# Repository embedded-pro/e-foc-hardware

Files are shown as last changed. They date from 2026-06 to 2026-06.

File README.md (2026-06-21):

# e-foc — Hardware





A three-phase brushless (BLDC / PMSM) motor driver board designed to run the
[**e-foc** Field-Oriented Control firmware](https://github.com/embedded-pro/e-foc).

This repository contains the **KiCad** electrical design — schematics, project
configuration and (eventually) the PCB layout — for the power and signal-chain
hardware that the e-foc control software targets. The microcontroller itself
lives on a pluggable module; this board provides the power stage, gate drive,
current sensing, protection and peripheral connectivity around it.

> **Scope:** this repo is the *hardware*. For the control algorithms (Clarke/Park
> transforms, Space Vector Modulation, current/velocity PID loops, auto-tuning),
> see the [firmware repository](https://github.com/embedded-pro/e-foc).

---

## Highlights

- **Three-phase inverter** built from three TI `CSD88537ND` 60 V dual NexFET™
  half-bridge power blocks (one per phase) — low R<sub>DS(on)</sub>, sized for a
  50 V bus at 5 A.
- **`FAN7888` 3-phase gate driver** with bootstrap high-side supply for clean,
  cross-conduction-protected switching.
- **Low-side shunt current sensing** (0.02 Ω) on each phase, amplified and
  filtered through a dedicated `TLV9062` / `TLV9064` analog conditioning stage
  for the controller's ADC.
- **Wide-input switching power supply** — `LM5164` 100 V synchronous buck plus
  `AMS1117` linear regulators generating the +15 V gate-drive rail, +5 V and
  +3.3 V logic rails, with TVS bus-clamp protection (`SMCJ51A`).
- **CAN connectivity** via an `SN65HVD230` transceiver for multi-axis /
  networked control.
- **Non-volatile storage** — `24LC04` I²C EEPROM (calibration / parameters) and
  `W25Q32` 32-Mbit SPI flash (logs / firmware assets).
- **MCU-agnostic carrier** — the controller plugs in over a 24-pin (2×12)
  header, matching the firmware's `PlatformFactory` abstraction (e.g. STM32F407
  or TI Tiva TM4C1294 modules).

---

## Board architecture

The design is organised as hierarchical schematic sheets, each a self-contained
functional block:

| Sheet | Function | Key parts |
|---|---|---|
| `e-foc.kicad_sch` | Top-level sheet wiring all blocks together | — |
| `power-supply` | Wide-input supply: gate-drive + logic rails, protection | `LM5164`, `AMS1117-3.3`, `SMCJ51A` (D1 bus TVS) |
| `driver` | Three-phase inverter, gate drive, phase shunts, motor terminals | `FAN7888`, 3× `CSD88537ND`, 0.02 Ω shunts |
| `adc-conditioner` | Current/voltage sense amplification & anti-alias filtering | `TLV9062`, `TLV9064` |
| `microcontroller-connector` | 2×12 header to the MCU module + signal break-out | `Conn_02x12` |
| `can-bus` | CAN field-bus interface | `SN65HVD230` |
| `serial-com` | Serial / debug communications | — |
| `eeprom-mem` | I²C EEPROM for calibration & parameters | `24LC04` |
| `flash-mem` | SPI NOR flash for logging / assets | `W25Q32JVSS` |

---

## Design requirements (spec)

These are the **hard design targets** the board must meet — the authoritative
requirements used for design review and sign-off.

| # | Requirement | Target |
|---|---|---|
| R1 | Input bus voltage | **50 V** max |
| R2 | Output current | **5 A** max continuous (DC) |
| R3 | Motor types | 3-phase brushless (BLDC) / PMSM, **FOC** control |
| R4 | PWM switching frequency | **50 kHz** max |
| R5 | Configuration storage | **EEPROM** available for parameters / calibration |
| R6 | Firmware-update storage | **External flash** for FW update |
| R7 | Field-bus | **CAN @ 1 Mbps** max, **GND present in the connector** |
| R8 | PCB stack-up | **2 layers** is sufficient |
| R9 | Position feedback | input for **encoder OR hall sensor** |

### As-built component capability

| Parameter | Value |
|---|---|
| Power topology | 3× half-bridge (1 dual FET per phase), low-side shunt sensing |
| Switching devices | TI `CSD88537ND`, 60 V dual N-channel NexFET™ half-bridge (Q1–Q3) — 10 V margin over the 50 V bus (R1) |
| Bus TVS clamp | D1 = `SMCJ51A`, 51 V standoff / 1500 W (see note below) |
| Gate driver | `FAN7888`, 3-phase, bootstrap high-side |
| Current sense | 0.02 Ω low-side shunt per phase + op-amp gain stage |
| Logic rails | +3.3 V logic + gate-drive rail (FAN7888 VDD) |
| Protection | TVS bus clamp (`SMCJ51A`), CAN ESD array, gate clamps |
| Comms | CAN (`SN65HVD230`, R7), serial / debug |
| Storage | I²C EEPROM (`24LC04`, R5), SPI flash (`W25Q32`, 32 Mbit, R6) |
| Controller | External 24-pin MCU module (STM32 / TI Tiva, via firmware abstraction) |

> **D1 TVS sizing.** The bus is 50 V max; the `CSD88537ND` is a 60 V FET. A
> standard TVS cannot both stand off 50 V *and* clamp below 60 V (clamp ratio
> ~1.5×), so `SMCJ51A` (Vrwm 51 V, Vbr ≥ 56.7 V, Vc ≈ 82 V) is chosen to absorb
> gross load-dump / inductive transients without conducting in normal operation.
> The 10 V FET margin against **switching ringing** must be held by layout —
> tight commutation loop, adequate bulk capacitance, and (if needed) an RC
> snubber — not by the TVS. Compliance with R1–R9 is confirmed during design
> review and bring-up.

---

## Repository layout

```
e-foc/
├── hardware/                            # KiCad projects — one folder per board
│   ├── e-foc/                           #   main motor-driver board
│   │   ├── e-foc.kicad_pro
│   │   ├── e-foc.kicad_sch              #     top-level (root) schematic
│   │   ├── e-foc.kicad_pcb              #     PCB layout
│   │   ├── sym-lib-table
│   │   ├── components/                  #     project symbol libs (e.g. CSD88537ND)
│   │   └── schematic/                   #     hierarchical sub-sheets
│   │       ├── power-supply.kicad_sch
│   │       ├── driver.kicad_sch
│   │       └── … adc-conditioner, can-bus, encoder, eeprom-mem,
│   │             flash-mem, microcontroller-connector, serial-com
│   └── tiva-80pin-adapter/              #   EK-TM4C1294XL ↔ e-foc adapter board
│       ├── tiva-80pin-adapter.kicad_pro
│       ├── tiva-80pin-adapter.kicad_sch
│       └── tiva-80pin-adapter.kicad_pcb
├── scripts/                            # export helpers (run per board)
│   ├── export_review.py                #   review package  -> review_exports/<board>/
│   └── export_jlcpcb.py                #   fab + assembly  -> manufacturing/<board>/
└── .github/workflows/                  # CI: kicad-bot.yml (quality gate) + release.yml
```

> Each board is a self-contained KiCad project in its own `hardware/<board>/`
> folder — the `.kicad_pro`, root schematic and board share that folder (KiCad
> locates them by name and path). Hierarchical sub-sheets and project symbol libs
> are referenced by relative path within the board folder. Generated outputs are
> gitignored and land under `review_exports/<board>/` and `manufacturing/<board>/`.

---

## Getting started

This is a [**KiCad 10**](https://www.kicad.org/) project.

1. Clone the repository:
   ```bash
   git clone https://github.com/embedded-pro/e-foc-hw.git
   cd e-foc-hw
   ```
2. Open `hardware/e-foc/e-foc.kicad_pro` (or
   `hardware/tiva-80pin-adapter/tiva-80pin-adapter.kicad_pro`) in KiCad.
3. Open the schematic editor to browse the hierarchical sheets, or the PCB
   editor for the board layout.

### Headless checks (the same ones CI runs)

With KiCad 8+ installed you can run electrical / design-rule checks locally:

```bash
kicad-cli sch erc  --output erc.json --format json hardware/e-foc/e-foc.kicad_sch
kicad-cli pcb drc  --output drc.json --format json hardware/e-foc/e-foc.kicad_pcb
```

Or use the export helpers (any board): `python scripts/export_review.py` for the
e-foc board, `python scripts/export_review.py --name tiva-80pin-adapter` for the
adapter; `scripts/export_jlcpcb.py` likewise for the fab/assembly package.

---

## Continuous integration

Every push and pull request that touches a schematic or board file is checked by
[**kicad-bot**](https://github.com/embedded-pro/kicad-bot) — a CI quality gate
that wraps `kicad-cli`, KiBot, KiCost and KiDiff to run:

- **ERC / DRC verification** — electrical and design-rule checks.
- **BOM availability** — distributor stock / lifecycle (end-of-life) flags.
- **Visual diffs** — schematic & PCB change previews on pull requests.

The workflow lives in [`.github/workflows/kicad-bot.yml`](.github/workflows/kicad-bot.yml)
and uploads a `kicad-bot-output/` artifact (report, metrics, raw violation data).

> kicad-bot is a CI guardrail, **not** a substitute for design review or sign-off.

To enable distributor BOM pricing/availability, add the relevant API keys as
repository secrets (`MOUSER_KEY`, `DIGIKEY_CLIENT_ID`, `DIGIKEY_CLIENT_SECRET`).

All third-party actions are **pinned to a full commit SHA** (with the version in a
trailing comment) for supply-chain hardening.

## Releases

Releases are automated with [release-please](https://github.com/googleapis/release-please)
and driven by [Conventional Commits](https://www.conventionalcommits.org/)
(`feat:`, `fix:`, …). The flow ([`.github/workflows/release.yml`](.github/workflows/release.yml)):

1. Commits to `main` keep an open **release PR** with the next version bump and
   `CHANGELOG.md` entries.
2. Merging that PR cuts a **GitHub Release** and tag.
3. On release, kicad-bot re-runs **ERC/DRC** (gating the release on a clean
   design), resolves the **BOM**, and produces **Gerbers / drill / position**
   files. These are zipped into `e-foc-hw-<version>.zip` and attached to the
   release as a downloadable fabrication package.

Version state is tracked in [`.release-please-manifest.json`](.release-please-manifest.json);
behaviour is configured in [`release-please-config.json`](release-please-config.json).

---

## License

Released under the [MIT License](LICENSE).

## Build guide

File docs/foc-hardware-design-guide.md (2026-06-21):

# FOC Motor-Driver Hardware Design Guide

> A **component-agnostic** body of knowledge for designing and reviewing a
> three-phase BLDC/PMSM Field-Oriented-Control power board. It captures what a
> senior power-electronics / embedded-hardware engineer checks when designing
> gate drives, MOSFET inverters, current sensing, switching supplies, protection
> and the PCB layout for high-di/dt power stages.
>
> Treat this guide as an **interface**, not an implementation. It describes the
> *functional blocks* (the power stage, gate driver, current sense, supply rails,
> protection) and the *parameters* that constrain them — never specific part
> numbers. Any board is one implementation of this interface; its concrete part
> choices and numeric targets live in that board's own **README / spec**, which
> is the binding contract. When this guide and a board's spec disagree, the
> **spec wins**.
>
> **Design parameters** (referenced throughout; a board's spec fixes their
> values): $V_{bus}$ = max DC bus voltage · $I_{ph}$ = max continuous phase
> current · $f_{sw}$ = PWM switching frequency · $V_{drv}$ = gate-drive rail ·
> $N_{layer}$ = PCB copper layers · $V_{(BR)DSS}$ = FET drain-source rating.

---

## Table of contents

1. [FOC power system overview](#1-foc-power-system-overview)
2. [DC bus & input power](#2-dc-bus--input-power)
3. [Power-supply rails (buck + LDO)](#3-power-supply-rails-buck--ldo)
4. [The three-phase inverter (H-bridge power stage)](#4-the-three-phase-inverter-h-bridge-power-stage)
5. [Gate drive](#5-gate-drive)
6. [Current sensing](#6-current-sensing)
7. [Protection: overvoltage, overcurrent, overtemperature](#7-protection-overvoltage-overcurrent-overtemperature)
8. [Thermal design](#8-thermal-design)
9. [PCB layout — the part that makes or breaks it](#9-pcb-layout--the-part-that-makes-or-breaks-it)
10. [KiCad workflow: tips & tricks](#10-kicad-workflow-tips--tricks)
11. [Design-review checklist](#11-design-review-checklist)
12. [References](#12-references)

---

## 1. FOC power system overview

Field-Oriented Control drives a 3-phase motor by synthesising sinusoidal phase
currents. The hardware's job is to (a) make a clean, low-impedance DC bus, (b)
switch that bus onto three motor phases with a MOSFET inverter, (c) measure the
phase currents accurately and in sync with the PWM, and (d) protect everything
when the motor or firmware misbehaves.

```
  Vbus ──┬─ bulk C ─┬───────────────┐  (high-di/dt power loop)
         │          │   ┌──────┐     │
   TVS  ===   buck →│   │  HS  │← gate│
   clamp  │  V_drv  │   ├──────┤ drive│  ← 3-φ gate driver (bootstrap HS supply)
         │  +5/3V3 │   │  LS  │     │
   GND ──┴──────────┴───┴──┬───┴─────┘
                           │ phase A/B/C → motor
                        Rshunt (low-side)
                           │
                        op-amp → ADC  (sampled at PWM centre)
```

The four signal domains — **power** (bus + phases), **gate drive** (fast,
high-dV/dt), **analog sense** (small-signal, noise-sensitive) and **logic/comms**
(MCU, CAN, memory) — must be deliberately partitioned. 90 % of FOC board failures
are not schematic errors; they are **layout** errors where one domain corrupts
another.

**The board's spec fixes the operating point** — the bus ceiling $V_{bus}$, the
continuous phase current $I_{ph}$, the PWM frequency $f_{sw}$, the stackup
$N_{layer}$, and the feedback type (encoder *or* hall). Read those from the
board's README/spec; this guide stays parametric so it applies to any of them.

---

## 2. DC bus & input power

### 2.1 Bus voltage and device margin

Pick switching devices with comfortable headroom over the **worst-case** bus,
not the nominal bus. The worst case is nominal + supply tolerance + **inductive
switching ringing** (the spike across the FET each time it turns off the motor's
inductance through the parasitic loop inductance).

- Example: a $V_{bus}$ of 50 V with a 60 V-rated FET leaves only **10 V (20 %)**
  of margin. That margin is consumed by ringing, so it must be *held by layout*
  (tight loop, bulk + local HF bypass, optional RC snubber) — **not** by the bus
  TVS, which clamps well above $V_{(BR)DSS}$ (see §7.1). A small $V_{(BR)DSS}$ −
  $V_{bus}$ margin is the single most layout-critical constraint on the power
  stage.
- Rule of thumb: target the steady bus at **≤ 80 %** of $V_{(BR)DSS}$, and keep
  the ringing peak below 100 %. If you cannot, raise the FET voltage class.

### 2.2 Bulk capacitance

The inverter draws pulsed current from the bus at the PWM frequency; the bus
caps supply that pulse so the source wiring doesn't have to. Two jobs:

1. **Bulk / electrolytic** — holds the bus stiff over a PWM cycle and absorbs
   energy when the motor regenerates (decelerates). Size for the **RMS ripple
   current**, not just capacitance. Inverter input-cap RMS ripple peaks near
   `Iripple,rms ≈ Iphase,rms × √(modulation factor)`; a practical first cut is
   `≈ 0.5 × Iphase,peak`. For a 5 A phase that is ~2.5 A RMS — choose an
   electrolytic/polymer rated for that ripple at $f_{sw}$ and temperature, or
   parallel several. Under-rated bulk caps run hot and dry out.
2. **High-frequency ceramic** — one or more low-ESL MLCCs (e.g. 100 nF–1 µF)
   placed **directly across each half-bridge** (drain of high-side FET to source
   of low-side FET) to carry the fast di/dt edge locally and kill ringing. This
   cap and the two FETs form the **commutation loop** — keep it physically tiny
   (§9.2). Derate MLCC voltage hard: rate the bypass MLCC at roughly **2×**
   $V_{bus}$ (e.g. ≥ 100 V X7R for a 50 V bus) because class-II ceramics lose
   most of their capacitance near rated voltage (DC-bias derating).

### 2.3 Inrush, reverse polarity, soft-start

- **Inrush:** charging the bulk caps at power-up is a near-short. For bench
  supplies a series NTC or a soft-start (pre-charge resistor bypassed by a
  MOSFET/relay after charge) prevents weld-on inrush and connector arcing.
- **Reverse polarity:** a series P-FET (or ideal-diode controller) protects the
  whole board from a flipped supply with far less drop than a Schottky.
- **UVLO:** make sure the gate-drive rail and logic come up *before* PWM is
  enabled, and that the gate driver's own UVLO holds the FETs off below the
  point where they would only partially enhance (high Rds(on) → thermal runaway).

---

## 3. Power-supply rails (buck + LDO)

A FOC board typically needs: the **gate-drive rail** $V_{drv}$ (commonly
10–15 V), **+5 V** (analog, CAN, sometimes the MCU) and **+3.3 V** (logic,
memories). A common topology derives these from a **wide-input synchronous buck**
feeding one or more **linear regulators (LDOs)**.

### 3.1 Wide-input buck

- **Why a buck rated well above $V_{bus}$?** Headroom for the same ringing/
  load-dump transients the FETs see. The buck's `VIN` pin sees the raw bus, so a
  regulator rated ~2× $V_{bus}$ survives the spike a marginal part would not.
- **Switch node** is the noisiest net on the board — high dV/dt. Keep its copper
  **small** (just big enough for current) to minimise the radiating/coupling
  area, and keep it away from analog sense traces.
- **Inductor** sized for the chosen ripple (typically 20–40 % of load). Keep the
  hot loop (VIN cap → high-side switch → inductor → output cap → GND) tight, just
  like the inverter commutation loop.
- **Feedback** divider tapped at the point of regulation; route FB away from the
  switch node and inductor; respect the datasheet's recommended FB placement.
- **Thermal:** check the buck's dropout, switching loss and junction temperature
  at the full logic + gate-drive load and worst-case ambient.

### 3.2 LDOs and sequencing

- LDOs are simple but **dissipative**: `P = (Vin − Vout) × Iload`. An LDO
  dropping 5 V → 3.3 V at 300 mA burns ~0.5 W — check the package thermal-pad
  copper. Don't feed an LDO directly from the high bus; cascade from the buck.
- **Dropout:** a typical LDO needs ~1–1.3 V of headroom — too much for a 3.3 V
  rail fed from a sagging 3.6 V source. Verify the input rail stays above
  Vout + dropout.
- **Analog rail:** give the op-amp / ADC reference rail its own filtered feed
  (ferrite bead + local cap, or a separate LDO) so PWM noise on the logic 3.3 V
  doesn't ride into the current-sense chain.
- **Sequencing:** logic before PWM enable (§2.3). If the logic rail and the
  gate-drive rail $V_{drv}$ come up in the wrong order, define the safe state
  (FETs off).

---

## 4. The three-phase inverter (H-bridge power stage)

Three half-bridges (one per phase) make the 3-phase inverter. Each half-bridge =
a high-side (HS) and low-side (LS) FET in totem-pole; their midpoint is the motor
phase. A common choice is **one dual-FET half-bridge package per phase** — the HS
and LS FET share one package, which already minimises the internal loop. Discrete
FETs work too, at the cost of a larger commutation loop to manage.

### 4.1 MOSFET selection criteria

| Parameter | What to check | Why it matters |
|---|---|---|
| **Vds / $V_{(BR)DSS}$** | ≥ $V_{bus}$ + ringing margin (§2.1) | a tight margin is layout-critical |
| **Rds(on)** | Conduction loss `Irms² · Rds(on)`; rises ~+0.4 %/°C — use the hot value | sets conduction heat at $I_{ph}$ |
| **Qg / Qgd** | Switching loss & gate-drive current; Qgd sets dV/dt & Miller risk | scales loss with $f_{sw}$ |
| **SOA / avalanche** | Survives the turn-off energy of the motor inductance | check `Eas` |
| **Body diode / Qrr** | Conducts dead-time; Qrr causes reverse-recovery spikes & shoot-through | dead-time & EMI |
| **Thermal (Rθjc/Rθja)** | Junction temp at full load; package thermal pad | pad must reach copper |

> **Footprint reality check.** Power FETs in SON/PowerPAK/DFN packages have a
> large bottom **thermal/source pad** that *is* the heatsink and a primary
> current path. Assigning a generic SOIC-8 land instead of the datasheet's
> recommended land pattern is a **MAJOR** error — it won't solder, the thermal
> path is broken, and Rds(on) effectively rises. Always match the BOM footprint
> to the datasheet package code and recommended land.

### 4.2 Conduction vs switching loss (per FET)

- **Conduction:** `P_cond = Irms² · Rds(on,hot)`. Use the data-sheet Rds(on) at
  the expected junction temperature, not 25 °C.
- **Switching:** `P_sw ≈ 0.5 · Vbus · Iphase · (t_on + t_off) · fsw + Qrr·Vbus·fsw`.
  At a few-tens-of-kHz $f_{sw}$ this is real but usually secondary to conduction;
  it grows fast with $V_{bus}$ and gate-resistor value.
- Sum HS+LS per phase, ×3 phases, and feed §8 (thermal).

### 4.3 Dead-time & shoot-through

If HS and LS conduct together for even an instant, the bus is shorted through
both FETs (**shoot-through**) — instant destruction. Prevent it with:

- **Dead-time:** a gap where both gates are low between HS and LS conduction.
  Many integrated 3-phase gate drivers provide internal dead-time and
  cross-conduction lockout; still verify the value vs the FET's turn-off +
  Miller-plateau time.
- Beware **dV/dt-induced turn-on** (Miller): when one FET switches, the fast
  dV/dt at the other FET's drain couples through Cgd and can momentarily turn it
  on. Mitigate with a low gate-off impedance, a **Miller clamp**, or a small
  gate-to-source resistor/cap (§5.3).

### 4.4 The commutation loop (most important power node)

The loop **bus-cap (+) → HS drain → HS channel → phase → LS channel → LS source
→ bus-cap (−)** carries the full switched di/dt. Its parasitic inductance `L_loop`
turns every turn-off into a voltage spike `V = L_loop · di/dt`. Minimising
`L_loop` is the #1 layout objective (§9.2) and is what protects the
$V_{(BR)DSS}$ − $V_{bus}$ FET margin.

---

## 5. Gate drive

The gate driver turns the FETs on/off fast enough to keep switching loss low, but
not so fast that ringing and EMI explode. The reference topology here is a
**3-phase gate driver with a bootstrap high-side supply**.

### 5.1 High-side bootstrap

The HS FET's source swings from 0 to the bus, so its gate must be driven
*relative to that moving source* — typically `Vgate = Vphase + V_drv`. A
**bootstrap** supply does this cheaply:

- When the LS FET is on (phase ≈ 0 V), the **bootstrap cap** `Cboot` charges from
  the gate rail through the **bootstrap diode** `Dboot`.
- When the HS FET turns on, `Cboot` floats up with the source and supplies the HS
  gate charge.

**Bootstrap cap sizing:** `Cboot ≥ Qtotal / ΔVboot`, where
`Qtotal ≈ Qg(HS) + Qrr(Dboot) + (Iqbs · t_on_max) + Qls_level_shift`, and ΔVboot
is the allowed droop (keep < a few hundred mV so the HS gate stays well above its
plateau). A common practical rule is `Cboot ≥ (10…50) · Qg / ΔVboot`; e.g. for
Qg ≈ 15 nC and ΔVboot ≈ 0.1 V, `Cboot ≥ 150 nF` → choose **1 µF** for margin.
Place `Cboot` right at the driver's VB/VS pins.

**Bootstrap diode:** fast-recovery, reverse voltage ≥ bus, low Qrr; sized for the
peak refresh current. A series resistor can limit the refresh inrush.

**Bootstrap refresh / 100 % duty limit:** the HS rail only recharges while the LS
FET conducts. Near 100 % duty (or a stalled rotor held in one position) the
bootstrap can starve. If the application needs sustained 100 % HS-on, use a
charge pump or isolated HS supply instead.

### 5.2 Gate resistors

The gate resistor `Rg` sets the switching speed and damps the gate-loop ringing
(driver output L + gate-loop L + Ciss form a resonant circuit).

- **Larger Rg:** slower edges → lower dV/dt, di/dt, EMI and overshoot, but more
  switching loss and heat. **Smaller Rg:** faster, more efficient, but more ring
  and Miller-induced turn-on risk.
- Often a **split** drive: a small `Rg(on)` via a diode for controlled turn-on and
  a smaller `Rg(off)` for fast, low-impedance turn-off (turn-off speed fights
  Miller shoot-through). Start from the driver/FET app-note value and tune on the
  bench with a scope on Vds and Vgs.

### 5.3 Miller clamp & negative drive

- **Miller (dV/dt) turn-on:** during the opposite FET's fast edge, Cgd injects
  current into the off FET's gate. A **strong pull-down** (low `Rg(off)`,
  dedicated clamp pin, or active Miller clamp) holds Vgs below threshold.
- On a tight low-voltage design a small gate-to-source resistor and minimal gate
  loop usually suffice; negative gate drive is reserved for higher-voltage SiC.

### 5.4 Layout coupling to the driver

Gate loops (`driver out → Rg → FET gate → FET source → driver return`) must be
**small and matched** between HS and LS, and routed away from the switch node.
Long, loopy gate traces pick up the phase dV/dt and cause false switching. Keep
the driver physically close to its FET block — this is a manufacturer-recommended
layout point you should verify against the gate-driver datasheet's layout section.

---

## 6. Current sensing

FOC needs accurate phase-current feedback, **time-aligned to the PWM**. Three
common topologies:

| Topology | Pros | Cons |
|---|---|---|
| **Low-side shunt** (in each LS source to GND) | Cheap, ground-referenced amp, no CM voltage | Only valid while LS FET is on → tight sample timing; misses current at high duty |
| **Inline / in-phase shunt** | Measures true phase current any time | Amp must reject the full phase common-mode swing (needs high-CMVR current-sense amp) |
| **Hall / magnetic** | Isolated, no I²R loss | Cost, offset/drift, bandwidth |

### 6.1 Shunt sizing

- **Resistance:** trade signal vs loss. A **20 mΩ** shunt gives `5 A → 100 mV`
  full-scale — a healthy signal for a modest-gain amp. Pick $R_{sh}$ so
  $I_{ph} · R_{sh}$ lands in the amp's comfortable input range.
- **Power:** `P = I² · R`. At 5 A through 20 mΩ: `25 · 0.02 = 0.5 W`; at a 7 A
  peak, ~1 W. Choose a **≥ 1 W, ideally 2 W (2512) low-inductance** shunt and
  give it copper to spread heat. Under-rated shunts drift with temperature and
  add error.
- **Tempco & inductance:** use a low-tempco (≤ 50 ppm/°C) metal-element shunt;
  current-sense resistors with low parasitic inductance avoid corrupting the
  fast LS-on current waveform.

### 6.2 Kelvin (4-wire) sensing

Sense the shunt voltage **across the element itself**, with two dedicated traces
landing on the shunt's inner sense points — *not* tapped off the high-current
copper. Any power-current copper between the tap points adds IR error. This
**Kelvin connection** is mandatory for a milliohm-scale shunt where trace
resistance is a large fraction of the shunt (§9.4).

### 6.3 Amplifier chain

A current-sense op-amp (or dedicated current-sense amplifier) conditions the
shunt signal before the ADC. Check:

- **Gain:** map full-scale current to the ADC range with margin (e.g. 100 mV ×
  gain ≈ 2–3 V into a 3.3 V ADC). For **low-side** shunts the measurement is
  ground-referenced and (per LS-on window) unipolar; the bidirectional phase
  current is reconstructed in firmware. For **inline** sensing the amp must be
  biased to mid-rail for bipolar current.
- **Bandwidth:** the amp + filter must settle within the ADC sampling window.
  Too little BW smears the current; too much passes switching noise. Set the
  anti-alias corner above the control bandwidth but below half the ADC rate.
- **Offset & CMRR:** op-amp `Vos` and gain error appear as current-measurement
  offset → torque ripple. Calibrate zero-current offset in firmware at startup.
- **Protection:** clamp/limit the amp inputs against the shunt's switching spikes;
  keep the filter caps close to the ADC pin.

### 6.4 Sampling in sync with PWM

Low-side sensing only sees phase current while the LS FET conducts, which is
around the **PWM cycle centre** (for centre-aligned PWM). The ADC trigger must
fire in that window. This is firmware + timer work, but the hardware must give
the amp enough bandwidth to settle before the sample and must not have so much
filter delay that the valid window closes. Document the expected sample instant so
firmware and hardware agree.

---

## 7. Protection: overvoltage, overcurrent, overtemperature

### 7.1 Overvoltage / transient (TVS, clamp ratio, snubbers)

Two different overvoltage problems, two different fixes:

1. **Gross bus transients** (load dump, long-lead inductive kick, hot-plug):
   absorbed by a **bus TVS**. Pick its standoff (Vrwm) just above $V_{bus}$ so it
   does not conduct in normal operation. Example: a 50 V bus pairs with a ~51 V
   standoff TVS whose clamp sits near ~82 V. The consequence: that **clamp is
   above a 60 V FET rating** — so the TVS protects the *board* from catastrophic
   transients but does **not** protect the FETs from fast switching ringing. Hold
   the FET margin with layout (below).
   - **Clamp ratio reality:** a silicon TVS clamps at roughly **1.4–1.6×** its
     standoff. You cannot both stand off $V_{bus}$ and clamp under a close
     $V_{(BR)DSS}$ with one TVS. If the FETs needed TVS protection you would need
     a higher-voltage FET class.
2. **Fast switching ringing** (every turn-off): controlled by **(a)** a small
   commutation loop, **(b)** local HF bypass MLCC at each half-bridge, **(c)**
   gate-resistor slowing, and optionally **(d)** an **RC snubber** across each
   half-bridge or the bus. Snubber design: `Rsnub ≈ √(L_loop/C_oss)`,
   `Csnub ≈ (2…4)·C_oss`; tune on the bench to critically damp the ring without
   excessive snubber loss `P = Csnub·Vbus²·fsw`.

### 7.2 Overcurrent (OCP)

Layers of defence, fastest first:

- **Hardware cycle-by-cycle / fault trip:** compare the shunt voltage (or a
  dedicated sense) against a threshold with a fast comparator that pulls the
  driver into shutdown / forces all FETs off within a PWM cycle. This catches
  short-circuit and shoot-through before the FET SOA is exceeded — software is too
  slow for a hard short.
- **Gate-driver fault / desat (if supported):** some drivers offer over-current
  or desaturation detection with a fault flag back to the MCU.
- **Firmware current limit:** the FOC loop limits commanded current
  continuously; this protects the motor and handles soft overloads, but is *not*
  the last line of defence against a dead short.
- **Fuse:** a series bus fuse (or the source's current limit) is the final,
  non-resettable backstop.

Define the trip level above the legitimate peak FOC current (including transient
overshoot) but below the FET/shunt SOA, and verify the response time.

### 7.3 Overtemperature (OTP)

- **NTC placement:** put a thermistor on the copper **next to the FET block /
  shunts** (the hot spots), read by an MCU ADC channel; fold its limit into the
  firmware fault logic (fold-back current, then shutdown).
- **FET/driver thermal shutdown:** rely on it as a backstop, not the primary
  limit — by the time the junction TSD trips, the part is already at its limit.
- On a low-layer-count board the FET package pad + thermal copper + vias *is* the
  heatsink; monitor it (§8).

### 7.4 ESD / EMC on I/O

- **CAN:** ESD array on CANH/CANL (transceivers carry some ruggedness, but cable
  ports want external protection); common-mode choke optional for EMC; bus
  termination per CAN spec; **keep GND present in the connector** so nodes share
  a reference.
- **Encoder/Hall:** series resistors + RC/ESD on the exposed connector pins;
  the cable is an antenna — filter at the connector.
- **Logic/SPI/I²C:** keep memory (EEPROM, SPI flash) decoupled and short; pull-up
  values per bus speed.

### 7.5 UVLO / safe-state

Every driver and rail should define the **FET-off safe state** for: power-up,
brown-out, gate-rail loss, and fault. Verify the FETs cannot be left half-on.

---

## 8. Thermal design

A 2-layer board has no inner planes, so **copper area + thermal vias** are the
heatsink. Budget the loss, then provide the copper.

1. **Loss budget:** sum per-FET conduction + switching (§4.2) across all 6 FET
   positions, plus shunt I²R (§6.1, ~3 × 0.5–1 W), plus buck/LDO loss (§3). For a
   typical low-voltage drive this is a few watts total — manageable in copper if
   spread.
2. **Copper as heatsink:** maximise pour around the FET drain/source pads and
   shunts; the package thermal pad must connect to a large pour, not a thin trace.
3. **Thermal vias:** stitch the FET/shunt thermal pads to the opposite-layer pour
   with an array of vias (e.g. 0.3 mm drill, ~1 mm pitch) to use both copper
   layers and the bottom-side air. More vias = lower Rθ.
4. **Verify junction temp:** `Tj = Ta + P · Rθja(as-laid-out)`. The datasheet
   Rθja assumes a reference copper area — your real number depends on your pour.
   Keep `Tj` below ~ 110–125 °C with margin at worst-case ambient.
5. **Hot-spot sensing:** §7.3 NTC closes the loop.

---

## 9. PCB layout — the part that makes or breaks it

> For a high-di/dt FOC stage, layout *is* the design. The schematic can be perfect
> and the board still fail from a loose commutation loop or a non-Kelvin shunt.
> This section is the priority order a senior engineer places components in.

### 9.1 Placement strategy ("first position" — do this first)

Place in this order, **power first**, before routing anything:

1. **Connectors & board outline fixed** — bus input, motor phase output, MCU
   header, CAN, encoder — at the edges where the harness wants them. These anchor
   everything.
2. **Power stage** — the three half-bridges (one dual-FET block per phase), their
   local HF bypass MLCCs, and the phase shunts. Arrange the three phases in a
   regular row so each commutation loop is identical and tiny. The bulk caps sit
   right at the FET drains.
3. **Gate driver** hugging the FET block, with `Cboot`/`Dboot` and gate resistors
   right at the driver, gate loops short and HS/LS matched.
4. **Current-sense amplifiers** close to their shunts with Kelvin taps; keep the
   analog group away from the switch nodes and gate loops.
5. **Buck regulator** with its own tight hot loop, switch node small, away from
   analog.
6. **Logic & comms** — MCU header, CAN transceiver, EEPROM/flash — in the quiet
   corner, fed by the filtered logic rails.

Group parts by schematic sheet; keep each functional block contiguous. Decide the
**grounding scheme now** (§9.5), not after routing.

### 9.2 Power commutation loop (the #1 rule)

Make the loop **bus-cap(+) → HS → phase → LS → bus-cap(−)** as small as physically
possible:

- Put the **HF bypass MLCC directly across the half-bridge** (HS drain to LS
  source), with the shortest, widest connection — it carries the di/dt edge.
- Keep the high-side drain, the FET package, and the low-side source/shunt return
  tightly clustered. On 2 layers, return the loop on the bottom layer **directly
  under** the top-layer power path so the go and return currents overlap and
  cancel inductance (image-plane effect).
- Every mm of loop is inductance; inductance × di/dt is the spike that eats the
  $V_{(BR)DSS}$ − $V_{bus}$ FET margin. This is where that margin is won or lost.

### 9.3 Gate loop

- Short, **matched** HS and LS gate loops; gate and gate-return run together
  (parallel/over each other) to minimise loop area.
- Route gate traces **away from** the switch node / phase copper; never run a gate
  trace under the phase pour where dV/dt couples in.
- Place `Rg`, `Cboot`, `Dboot` at the driver pins.

### 9.4 Kelvin current sense

- Tap the shunt at its dedicated **sense terminals**, with two thin traces routed
  as a **tight differential pair** straight to the amplifier — no power current
  between the taps.
- Keep these traces short, away from gate/switch nodes, guarded by analog ground.
- The amplifier's reference/return lands at the **single analog-ground point**,
  not on the noisy power ground (§9.5).

### 9.5 Grounding (star / single-point on 2 layers)

- Separate **power ground** (bulk-cap return, FET sources, shunt high-current
  side) from **analog ground** (amp refs, ADC, filter caps) and **digital ground**
  (MCU, memories, CAN logic) in your mind and on the copper.
- Join them at **one point** — the natural choice is at the shunt/ADC-reference
  region so the current-sense return is clean. Avoid loops where power return
  current flows through analog-ground copper.
- On a 2-layer board the bottom layer is your ground strategy: a mostly-solid
  bottom **ground pour** under the power and analog sections gives the return
  path and the image plane (§9.2). Don't let high-di/dt power return and quiet
  analog return share the *same* copper region without a deliberate single tie.

### 9.6 Copper pours / planes

- **Power pours:** wide, solid copper for bus +, phases, and grounds; size for
  current (§10.4). Connect power-FET and shunt pads to pours with **solid**
  copper (no thermal-relief spokes) so you don't choke current or heat.
- **Ground pour:** fill the bottom layer; stitch top and bottom grounds with
  vias, especially around the power loop and along board edges.
- **Clearance & slivers:** set zone clearance to your fab's minimum (§10) and
  enable island/sliver removal so the pour doesn't leave unconnected copper
  fragments or acid traps.
- **Switch-node pour:** keep it just large enough for current; do **not** flood a
  big switch-node pour (it radiates).

### 9.7 High-voltage spacing (creepage & clearance)

- Apply IPC-2221 spacing for the $V_{bus}$ and phase nets — at tens of volts the
  electrical minimum is small, but give generous spacing at connectors and under
  the FETs for manufacturability and transient margin.
- Keep enough **edge clearance** (copper to board edge) for the fab and for HV
  creepage to mounting hardware.

### 9.8 Decoupling & filtering placement

- Every IC's bypass cap **at its supply pin**, smallest value closest.
- Analog rail filtered (ferrite + cap) separately from logic (§3.2).
- Filter cable ports (CAN, encoder) **at the connector** (§7.4).

### 9.9 Mechanical & assembly

- Mounting holes / stack-mate connectors positioned per the mechanical stack —
  when the board mates to another (adapter, carrier, or controller board), the
  connectors and holes must register; see the stack-mate notes in the reviewer
  agent.
- Fiducials for assembly, polarity marks on silk, test points on key nets
  (bus, rails, phase, shunt, faults) for bring-up.

---

## 10. KiCad workflow: tips & tricks

Practical KiCad (v8–v10) steps for getting a clean, fabricable board.

### 10.1 Schematic & ERC first

- **Power symbols & `PWR_FLAG`:** every supply net needs a source. KiCad's ERC
  flags "input power not driven" until you place a `PWR_FLAG` on rails fed from
  connectors/regulals outputs. Don't silence the error by deleting it — place the
  flag where power genuinely enters.
- **Net labels everywhere:** name bus, phase, gate, sense and rail nets
  explicitly; it prevents accidental merges and makes the PCB readable. Watch for
  **aliased/merged sense nets** (e.g. three phase-shunt returns accidentally on
  one net) — a classic FOC ERC/derived bug.
- **No-connect flags** on intentionally unused pins; correct **pin electrical
  types** on hierarchical sheet pins so ERC's input/output/power checks are
  meaningful.
- Run **ERC clean** (or every remaining item justified) before layout. Treat ERC
  as design intent verification, not noise.

### 10.2 Component placement order (mirrors §9.1)

- Lock the board outline and connectors, then place power → gate → sense → buck →
  logic. Use **Place Footprints by sheet** / cross-probe from schematic to keep
  blocks together.
- Set the **drill/aux origin** to a board corner early — the assembly CPL export
  references it (the `scripts/export_jlcpcb.py` CPL must be board-relative, not
  page-space, or JLCPCB has to re-align it).

### 10.3 Net classes (set widths & clearances by function)

- Define net classes in **Board Setup → Net Classes**: e.g. `Power` (bus/phase,
  wide tracks, large clearance), `Gate`, `Analog`, `Default/Logic`.
- Assign track width and clearance per class so the autorouter/DRC enforce your
  current and isolation intent. This is faster and safer than hand-setting each
  trace.

### 10.4 Track width vs current (IPC-2152)

- Rough external-layer guide (1 oz / 35 µm copper, ~10 °C rise): **~0.5 A per
  10 mil (0.25 mm)** of width as a starting point.
  - ~1 A → ~12 mil (0.3 mm)
  - ~3 A → ~40 mil (1.0 mm)
  - **~5 A → ~100–120 mil (2.5–3.0 mm)** (size bus/phase for $I_{ph}$)
- Use **2 oz copper** to roughly halve the required width if the power copper is
  crowded — note the cost/fab implication. Always confirm against an IPC-2152
  calculator for your copper weight, rise and layer (internal traces need more).

### 10.5 Via sizing & current

- A single 0.3 mm-drill via carries roughly **~1 A** at a modest rise — use
  **arrays of vias** for power nets and thermal pads, never one via for a 5 A net.
- Stitch ground pours and FET/shunt thermal pads with via fields (§8).

### 10.6 Copper zones (pours)

- **Connection style:** set power/thermal pads to **solid** zone connection (no
  thermal spokes) so current/heat aren't choked; use thermal relief only where
  hand-soldering ease matters on signal pads.
- **Zone clearance / min width:** set to your fab minimum (§10.8); enable
  **remove islands** to delete orphan copper and avoid slivers/acid traps.
- **Zone priority & two grounds:** give overlapping zones explicit priority;
  keep analog-ground and power-ground zones distinct with the single tie (§9.5).
- **Refill (`B`) and re-run DRC** after every change — KiCad pours are not live by
  default; a stale pour hides shorts/clearance errors.

### 10.7 Teardrops

- Add **teardrops** (Route → ... / Board Setup → Teardrops in v7+, or the
  teardrop dialog) where tracks meet pads/vias. Benefits: mechanical strain
  relief, better drill-to-track registration, fewer acid traps, and a smoother
  current path on power tracks.
- Enable for vias and pads on the power nets especially; verify they don't create
  clearance violations on dense areas, then re-run DRC.

### 10.8 Design rules → match the fab (and DRC)

- Set **Board Setup → Constraints / Design Rules** to your fab's *standard* tier
  to stay cheap. Typical JLCPCB 2-layer standard (verify live — these change):
  min track/space **~0.127 mm (5 mil)** (6 mil is safest/cheapest), min drill
  **~0.2–0.3 mm**, min annular ring **~0.13 mm**, min hole-to-hole, min silk
  width **~0.15 mm**. Seeed Fusion is comparable — check both capability pages.
- Find the **single tightest rule** that would push you into an "advanced" price
  tier and relax it if you can.
- **Run DRC (`Inspect → Design Rules Checker`) to zero** before fab. Categorise:
  - *Clearance / track-width* — real, fix.
  - *Unconnected items* — real, route or intentionally tie.
  - *Schematic parity* — board doesn't match schematic; fix before trusting nets.
  - *Silk over pad / silk clipped* — cosmetic but fix for legibility & mask.
  - *Courtyard overlap* — placement/assembly risk.
- Locate each violation in the layout (KiCad zooms to it) and resolve or annotate.

### 10.9 Solder mask & paste

- **Mask expansion:** keep the default unless a part needs mask-defined pads;
  over-large expansion on fine-pitch parts bridges.
- **Mask slivers / web:** between close pads (fine-pitch IC, the FET pad fingers)
  the mask web can fall below the fab's minimum and peel — DRC/fab check flags
  this; widen pad spacing or accept a mask-defined region.
- **Via tenting:** tent (cover) vias under parts and in pours to stop solder
  wicking and shorts; leave test-point vias open.
- **Paste (stencil):** for the **FET/regulator thermal pads**, use a *windowpane*
  (segmented) paste aperture (~60–80 % coverage), not a single big opening, to
  avoid the part floating on a solder ball and tombstoning — check the assembly
  paste layer (`*.gtp/*.gbp`) reflects this.

### 10.10 Silkscreen & fab outputs

- Keep silk **off pads and mask openings**; meet the fab's min line width/height;
  add polarity marks, pin-1, refdes, and a board version/date.
- Export the **fab package** with `scripts/export_jlcpcb.py` and sanity-check:
  gerbers complete (copper/mask/paste/silk/Edge.Cuts/PTH+NPTH drill), **BOM has
  LCSC part numbers** for every assembled line, and the **CPL origin** is
  board-relative (§10.2). Generate the **review package** with
  `scripts/export_review.py` and look at the rendered PCB images before sign-off.

---

## 11. Design-review checklist

A condensed go/no-go list (the reviewer agent expands on this):

**Spec & devices**
- [ ] FET $V_{(BR)DSS}$ ≥ $V_{bus}$ + ringing margin; a tight margin is held by layout, not the TVS.
- [ ] FET/driver/regulator operating points inside datasheet recommended ranges.
- [ ] **Footprint matches the real package land** (esp. SON/PowerPAK FETs, thermal pad).
- [ ] Shunt power rating ≥ I²R at peak with margin; low tempco/inductance.
- [ ] TVS stands off $V_{bus}$ and is understood to clamp above the FET (board, not FET, protection).
- [ ] Bootstrap cap/diode sized; 100 %-duty/refresh case considered.

**Protection**
- [ ] Overcurrent: fast hardware trip + firmware limit + fuse backstop, level set below SOA.
- [ ] Overtemp: NTC at hot spots into firmware fold-back/shutdown.
- [ ] UVLO / safe-state defines FETs-off on power-up, brown-out, fault.
- [ ] ESD/filtering on CAN, encoder/hall, and cable ports.

**Layout**
- [ ] Commutation loop tiny; local HF bypass across each half-bridge; bottom-layer image return.
- [ ] Gate loops short & HS/LS matched, away from switch node.
- [ ] Kelvin shunt taps; analog ground single-point tie at sense/ADC ref.
- [ ] Power copper sized for $I_{ph}$ (IPC-2152); via arrays on power & thermal pads.
- [ ] Thermal copper + vias for FETs/shunts; junction-temp budget OK.
- [ ] Star/single-point ground; switch-node copper minimised.

**Manufacturing (KiCad/fab)**
- [ ] ERC clean (PWR_FLAGs placed, no merged sense nets).
- [ ] DRC clean and matched to fab standard tier; tightest cost-driving rule known.
- [ ] Pours refilled; islands removed; teardrops added on power nets.
- [ ] Mask webs/slivers OK; thermal-pad paste windowpaned; vias tented as needed.
- [ ] Drill/aux origin set; CPL board-relative; BOM has LCSC numbers; gerbers complete.
- [ ] Stack-mate connectors/holes register with the mating board(s).

---

## 12. References

Verify ratings against the live datasheet/app-note — numbers here are for
orientation and may change.

**Functional blocks** (this guide is component-agnostic — pick parts that meet
each block's interface; a board's README lists its concrete choices)
- **Power stage** — dual-FET half-bridge (one per phase), $V_{(BR)DSS}$ > $V_{bus}$.
- **Gate driver** — 3-phase, bootstrap high-side, internal dead-time.
- **Buck regulator** — wide-input synchronous buck, rated ~2× $V_{bus}$.
- **Current-sense amplifier** — low-offset op-amp / current-sense amp.
- **Bus TVS** — standoff just above $V_{bus}$ (see §7.1 clamp-ratio note).
- **CAN transceiver**, **I²C EEPROM**, **SPI NOR flash** — comms & storage.

**Standards & app-notes (general)**
- **IPC-2152** — conductor current-carrying capacity (track width vs current).
- **IPC-2221** — generic PCB design, spacing/creepage/clearance.
- Gate-driver / power-stage **layout app-notes** from the chosen driver & FET
  vendors (commutation loop, bootstrap, Kelvin sense, decoupling) — pull the
  specific parts' layout sections during review.
- **JLCPCB** capabilities (jlcpcb.com/capabilities) and **Seeed Fusion** PCB
  capabilities — manufacturability limits; verify live, they change.

---

> **For the reviewer agent:** treat §11 as the checklist, §7/§9 as the
> power-electronics rationale, and §10 as the KiCad/manufacturability basis. This
> guide is component-agnostic; the board's own README/spec remains the binding
> contract (specific parts and numeric targets), and this guide explains the
> *why* behind each check.

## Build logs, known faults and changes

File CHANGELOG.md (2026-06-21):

# Changelog

## [1.0.1](https://github.com/embedded-pro/e-foc-hardware/compare/v1.0.0...v1.0.1) (2026-06-21)

### Documentation

* add component-agnostic FOC hardware design guide ([#7](https://github.com/embedded-pro/e-foc-hardware/issues/7)) ([76e1a1b](https://github.com/embedded-pro/e-foc-hardware/commit/76e1a1b8b6380af448fc54e0bac3040ca1732bbb))

### Miscellaneous Chores

* drop release-as pin after v1.0.0 ([#5](https://github.com/embedded-pro/e-foc-hardware/issues/5)) ([34c9bd2](https://github.com/embedded-pro/e-foc-hardware/commit/34c9bd25560fa8ef2a9b301d3db43379bd841dd0))

## [1.0.0](https://github.com/embedded-pro/e-foc-hardware/compare/v0.1.0...v1.0.0) (2026-06-21)

### Miscellaneous Chores

* add release please action ([#1](https://github.com/embedded-pro/e-foc-hardware/issues/1)) ([db16d6d](https://github.com/embedded-pro/e-foc-hardware/commit/db16d6dcb76c7407000fbb325bc37b737838238d))
* enable all commit types and cut v1.0.0 ([#3](https://github.com/embedded-pro/e-foc-hardware/issues/3)) ([156ca4a](https://github.com/embedded-pro/e-foc-hardware/commit/156ca4a66b99c9d6906aff78070c2b5f0730bea4))

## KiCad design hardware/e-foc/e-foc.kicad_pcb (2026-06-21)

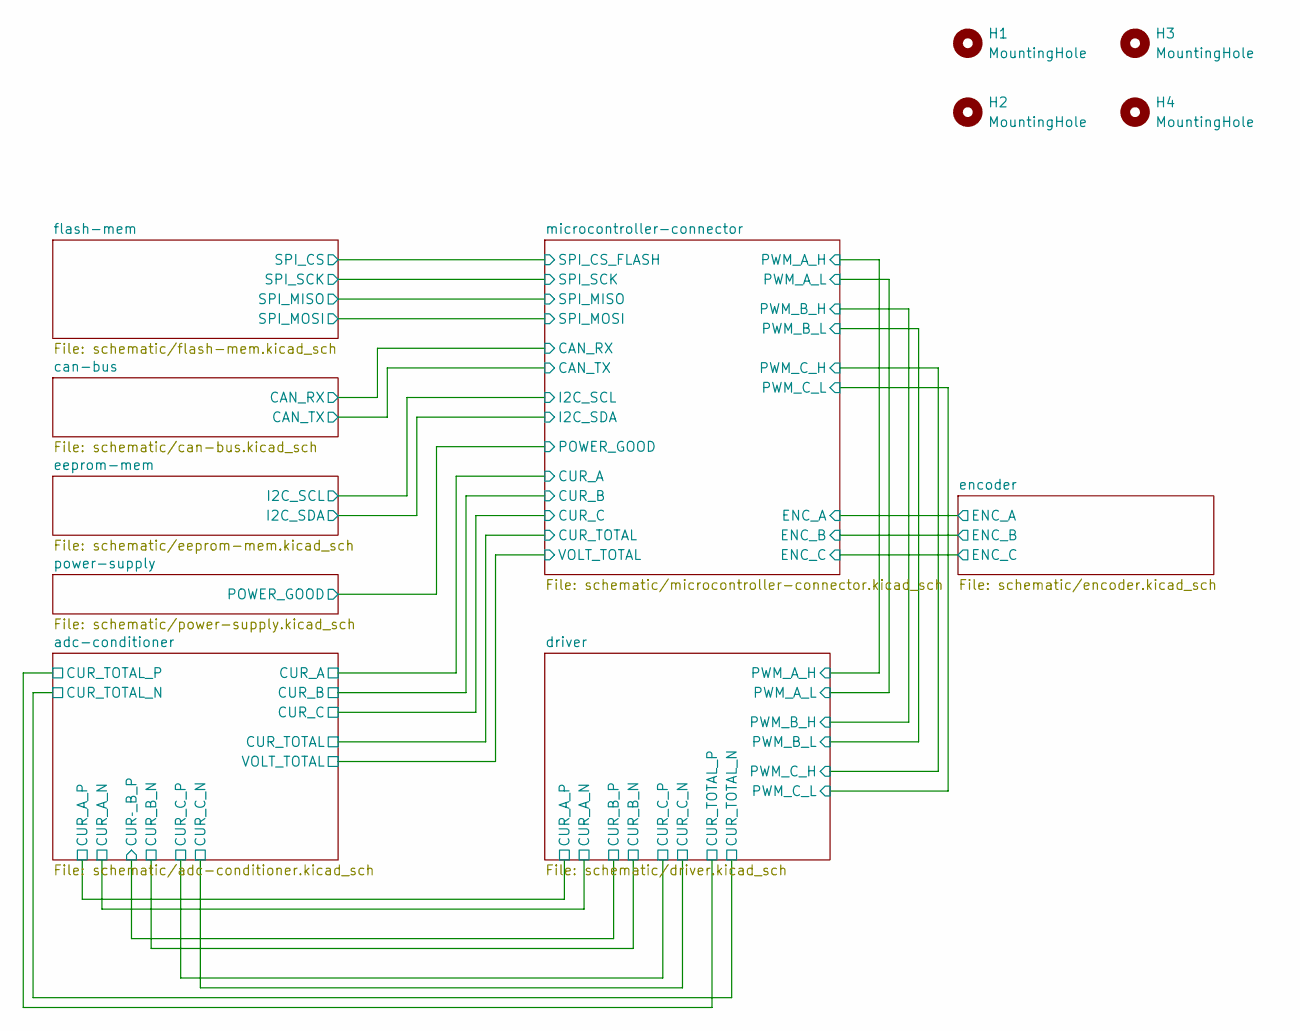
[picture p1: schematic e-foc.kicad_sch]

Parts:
H1, H2, H3, H4: MountingHole; MountingHole_3.2mm_M3_DIN965_Pad_TopBottom

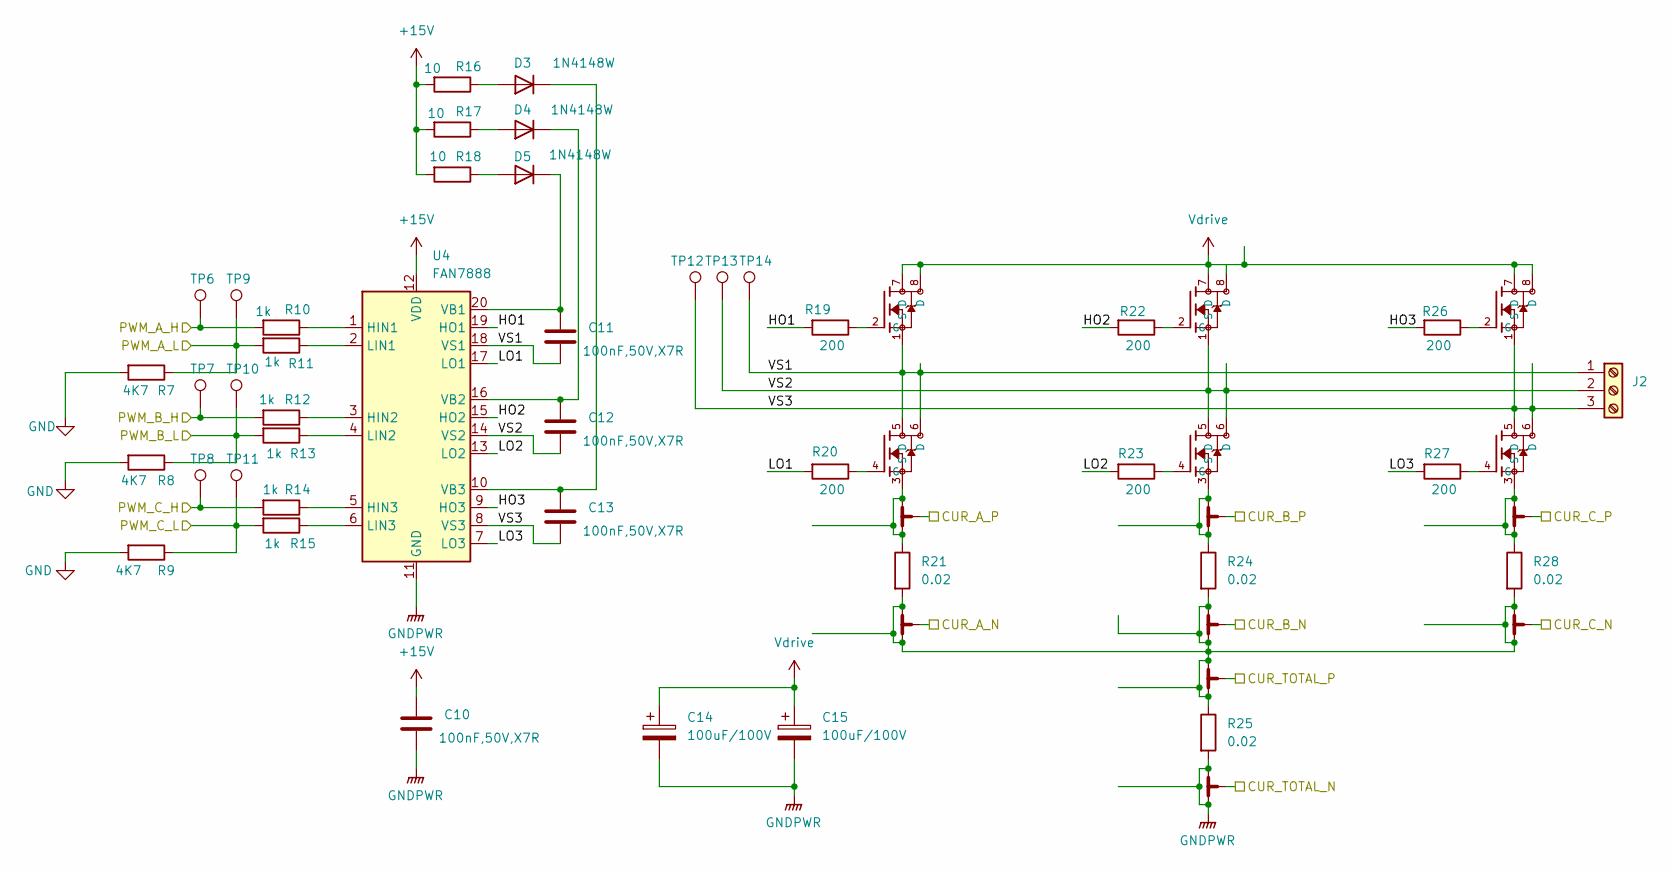
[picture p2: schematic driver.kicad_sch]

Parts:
C10: 100nF,50V,X7R; C_0805_2012Metric_Pad1.18x1.45mm_HandSolder
C11, C12, C13: 100nF,50V,X7R; C_1206_3216Metric_Pad1.33x1.80mm_HandSolder
C14, C15: 100uF/100V; CP_Elec_10x10.5
D3, D4, D5: 1N4148W; D_SOD-123
J2: Screw_Terminal_01x03; TerminalBlock_CUI_TB007-508-03_1x03_P5.08mm_Horizontal
NT2, NT3, NT4, NT5, NT6, NT7, NT8, NT9: NetTie_3_Tee; NetTie-3_SMD_Pad0.5mm
Q1, Q2, Q3: CSD88537ND; SOIC-8_3.9x4.9mm_P1.27mm
R7, R8, R9: 4K7; R_0805_2012Metric_Pad1.20x1.40mm_HandSolder
R10, R11, R12, R13, R14, R15: 1k; R_0805_2012Metric_Pad1.20x1.40mm_HandSolder
R16, R17, R18: 10; R_0805_2012Metric_Pad1.20x1.40mm_HandSolder
R19, R20, R22, R23, R26, R27: 200; R_0805_2012Metric_Pad1.20x1.40mm_HandSolder
R21, R24, R25, R28: 0.02; R_2512_6332Metric_Pad1.40x3.35mm_HandSolder
TP6, TP7, TP8, TP9, TP10, TP11, TP12, TP13, TP14: TestPoint; TestPoint_Pad_1.0x1.0mm
U4: FAN7888; SOIC-20W_7.5x12.8mm_P1.27mm

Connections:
+15V: C10.1, R16.2, R17.2, R18.2, U4.12 (VDD); also elsewhere on the board
/adc-conditioner/CUR_A_N: NT3.3; also elsewhere on the board
/adc-conditioner/CUR_A_P: NT2.3; also elsewhere on the board
/adc-conditioner/CUR_B_N: NT5.3; also elsewhere on the board
/adc-conditioner/CUR_C_N: NT9.3; also elsewhere on the board
/adc-conditioner/CUR_C_P: NT8.3; also elsewhere on the board
/adc-conditioner/CUR_TOTAL_N: NT7.3; also elsewhere on the board
/adc-conditioner/CUR_TOTAL_P: NT6.3; also elsewhere on the board
/adc-conditioner/CUR­_B_P: NT4.3; also elsewhere on the board
/driver/HO1: R19.2, U4.19 (HO1)
/driver/HO2: R22.2, U4.15 (HO2)
/driver/HO3: R26.2, U4.9 (HO3)
/driver/LO1: R20.2, U4.17 (LO1)
/driver/LO2: R23.2, U4.13 (LO2)
/driver/LO3: R27.2, U4.7 (LO3)
/driver/PWM_A_H: R10.2, TP6.1 (1_1); also elsewhere on the board
/driver/PWM_A_L: R7.1, R11.2, TP9.1 (1_1); also elsewhere on the board
/driver/PWM_B_H: R12.2, TP7.1 (1_1); also elsewhere on the board
/driver/PWM_B_L: R8.1, R13.2, TP10.1 (1_1); also elsewhere on the board
/driver/PWM_C_H: R14.2, TP8.1 (1_1); also elsewhere on the board
/driver/PWM_C_L: R9.1, R15.2, TP11.1 (1_1); also elsewhere on the board
/driver/VS1: C11.2, J2.1, Q1.1 (S), Q1.5 (D), Q1.6 (D), TP14.1 (1_1), U4.18 (VS1)
/driver/VS2: C12.2, J2.2, Q2.1 (S), Q2.5 (D), Q2.6 (D), TP13.1 (1_1), U4.14 (VS2)
/driver/VS3: C13.2, J2.3, Q3.1 (S), Q3.5 (D), Q3.6 (D), TP12.1 (1_1), U4.8 (VS3)
GND: R7.2, R8.2, R9.2; also elsewhere on the board
GNDPWR: C10.2, C14.2, C15.2, NT7.1, NT7.2, R25.2, U4.11 (GND); also elsewhere on the board
unnamed: D3.2 (A), R16.1
unnamed: C13.1, D3.1 (K), U4.10 (VB3)
unnamed: D4.2 (A), R17.1
unnamed: C12.1, D4.1 (K), U4.16 (VB2)
unnamed: D5.2 (A), R18.1
unnamed: C11.1, D5.1 (K), U4.20 (VB1)
unnamed: NT2.1, NT2.2, Q1.3 (S), R21.1
unnamed: NT3.1, NT3.2, NT5.1, NT5.2, NT6.1, NT6.2, NT9.1, NT9.2, R21.2, R24.2, R25.1, R28.2
unnamed: NT4.1, NT4.2, Q2.3 (S), R24.1
unnamed: NT8.1, NT8.2, Q3.3 (S), R28.1
unnamed: Q1.2 (G), R19.1
unnamed: Q1.4 (G), R20.1
unnamed: Q2.2 (G), R22.1
unnamed: Q2.4 (G), R23.1
unnamed: Q3.2 (G), R26.1
unnamed: Q3.4 (G), R27.1
unnamed: R10.1, U4.1 (HIN1)
unnamed: R12.1, U4.3 (HIN2)
unnamed: R14.1, U4.5 (HIN3)
unnamed: R11.1, U4.2 (LIN1)
unnamed: R13.1, U4.4 (LIN2)
unnamed: R15.1, U4.6 (LIN3)
Vdrive: C14.1, C15.1, Q1.7 (D), Q1.8 (D), Q2.7 (D), Q2.8 (D), Q3.7 (D), Q3.8 (D); also elsewhere on the board

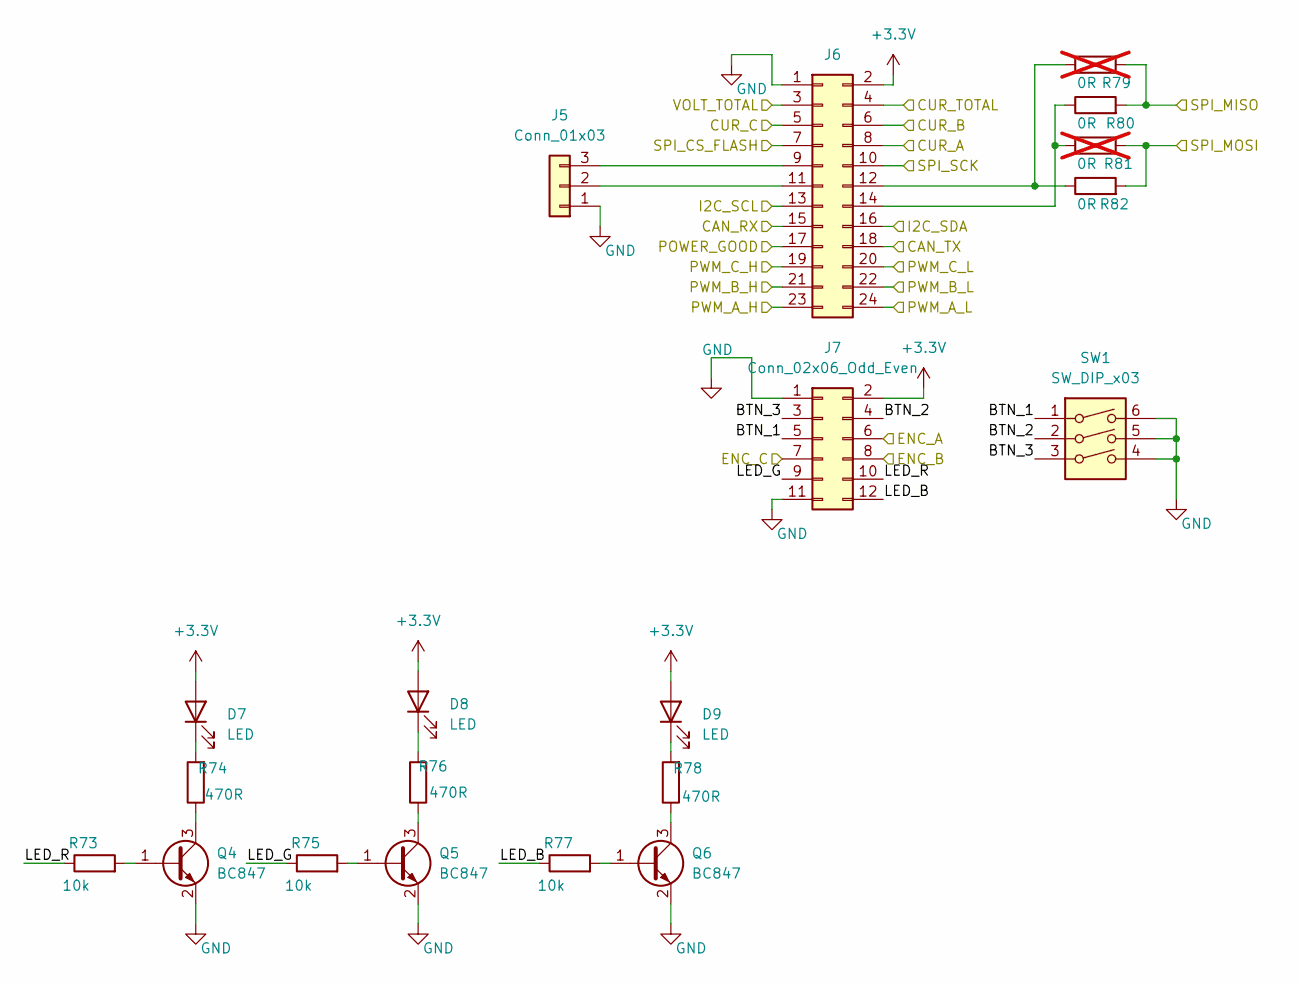
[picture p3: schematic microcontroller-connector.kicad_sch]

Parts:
D7, D8, D9: LED; LED_0805_2012Metric_Pad1.15x1.40mm_HandSolder
J5: Conn_01x03; PinHeader_1x03_P2.54mm_Vertical
J6: Conn_02x12_Odd_Even; PinHeader_2x12_P2.54mm_Vertical
J7: Conn_02x06_Odd_Even; PinHeader_2x06_P2.54mm_Vertical
Q4, Q5, Q6: BC847; SOT-23W_Handsoldering
R73, R75, R77: 10k; R_0805_2012Metric_Pad1.20x1.40mm_HandSolder
R74, R76, R78: 470R; R_0805_2012Metric_Pad1.20x1.40mm_HandSolder
R79, R81: 0R; R_0805_2012Metric_Pad1.20x1.40mm_HandSolder; not fitted
R80, R82: 0R; R_0805_2012Metric_Pad1.20x1.40mm_HandSolder
SW1: SW_DIP_x03; SW_DIP_SPSTx03_Slide_6.7x9.18mm_W8.61mm_P2.54mm_LowProfile

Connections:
+3.3V: D7.2 (A), D8.2 (A), D9.2 (A), J6.2, J7.2; also elsewhere on the board
/adc-conditioner/CUR_A: J6.8; also elsewhere on the board
/adc-conditioner/CUR_B: J6.6; also elsewhere on the board
/adc-conditioner/CUR_C: J6.5; also elsewhere on the board
/adc-conditioner/CUR_TOTAL: J6.4; also elsewhere on the board
/adc-conditioner/VOLT_TOTAL: J6.3; also elsewhere on the board
/can-bus/CAN_RX: J6.15; also elsewhere on the board
/can-bus/CAN_TX: J6.18; also elsewhere on the board
/driver/PWM_A_H: J6.23; also elsewhere on the board
/driver/PWM_A_L: J6.24; also elsewhere on the board
/driver/PWM_B_H: J6.21; also elsewhere on the board
/driver/PWM_B_L: J6.22; also elsewhere on the board
/driver/PWM_C_H: J6.19; also elsewhere on the board
/driver/PWM_C_L: J6.20; also elsewhere on the board
/eeprom-mem/I2C_SCL: J6.13; also elsewhere on the board
/eeprom-mem/I2C_SDA: J6.16; also elsewhere on the board
/encoder/ENC_A: J7.6; also elsewhere on the board
/encoder/ENC_B: J7.8; also elsewhere on the board
/encoder/ENC_C: J7.7; also elsewhere on the board
/flash-mem/SPI_CS: J6.7; also elsewhere on the board
/flash-mem/SPI_MISO: R79.2, R80.2; also elsewhere on the board
/flash-mem/SPI_MOSI: R81.2, R82.2; also elsewhere on the board
/flash-mem/SPI_SCK: J6.10; also elsewhere on the board
/microcontroller-connector/BTN_1: J7.5, SW1.1
/microcontroller-connector/BTN_2: J7.4, SW1.2
/microcontroller-connector/BTN_3: J7.3, SW1.3
/microcontroller-connector/LED_B: J7.12, R77.1
/microcontroller-connector/LED_G: J7.9, R75.1
/microcontroller-connector/LED_R: J7.10, R73.1
/microcontroller-connector/POWER_GOOD: J6.17; also elsewhere on the board
GND: J5.1, J6.1, J7.1, J7.11, Q4.2 (E), Q5.2 (E), Q6.2 (E), SW1.4, SW1.5, SW1.6; also elsewhere on the board
unnamed: D7.1 (K), R74.2
unnamed: D8.1 (K), R76.2
unnamed: D9.1 (K), R78.2
unnamed: J5.2, J6.11
unnamed: J5.3, J6.9
unnamed: J6.12, R79.1, R82.1
unnamed: J6.14, R80.1, R81.1
unnamed: Q4.1 (B), R73.2
unnamed: Q4.3 (C), R74.1
unnamed: Q5.1 (B), R75.2
unnamed: Q5.3 (C), R76.1
unnamed: Q6.1 (B), R77.2
unnamed: Q6.3 (C), R78.1

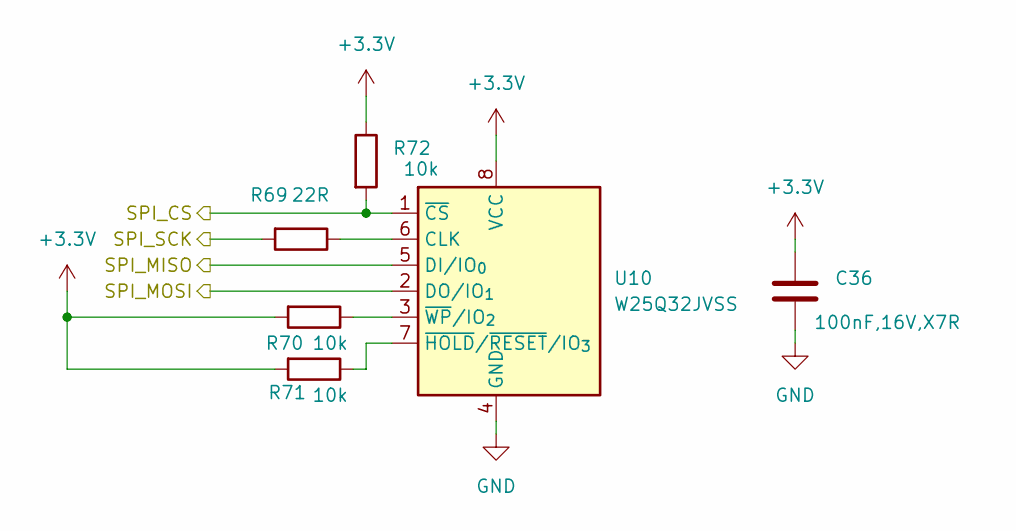
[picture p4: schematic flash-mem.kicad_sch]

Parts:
C36: 100nF,16V,X7R; C_0805_2012Metric_Pad1.18x1.45mm_HandSolder
R69: 22R; R_0805_2012Metric_Pad1.20x1.40mm_HandSolder
R70, R71, R72: 10k; R_0805_2012Metric_Pad1.20x1.40mm_HandSolder
U10: W25Q32JVSS; SOIC-8_5.3x5.3mm_P1.27mm

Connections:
+3.3V: C36.1, R70.2, R71.2, R72.1, U10.8 (VCC); also elsewhere on the board
/flash-mem/SPI_CS: R72.2, U10.1 (~CS); also elsewhere on the board
/flash-mem/SPI_MISO: U10.5 (DI/IO_{0}); also elsewhere on the board
/flash-mem/SPI_MOSI: U10.2 (DO/IO_{1}); also elsewhere on the board
/flash-mem/SPI_SCK: R69.2; also elsewhere on the board
GND: C36.2, U10.4 (GND); also elsewhere on the board
unnamed: R69.1, U10.6 (CLK)
unnamed: R71.1, U10.7 (~HOLD/~RESET/IO_{3})
unnamed: R70.1, U10.3 (~WP/IO_{2})

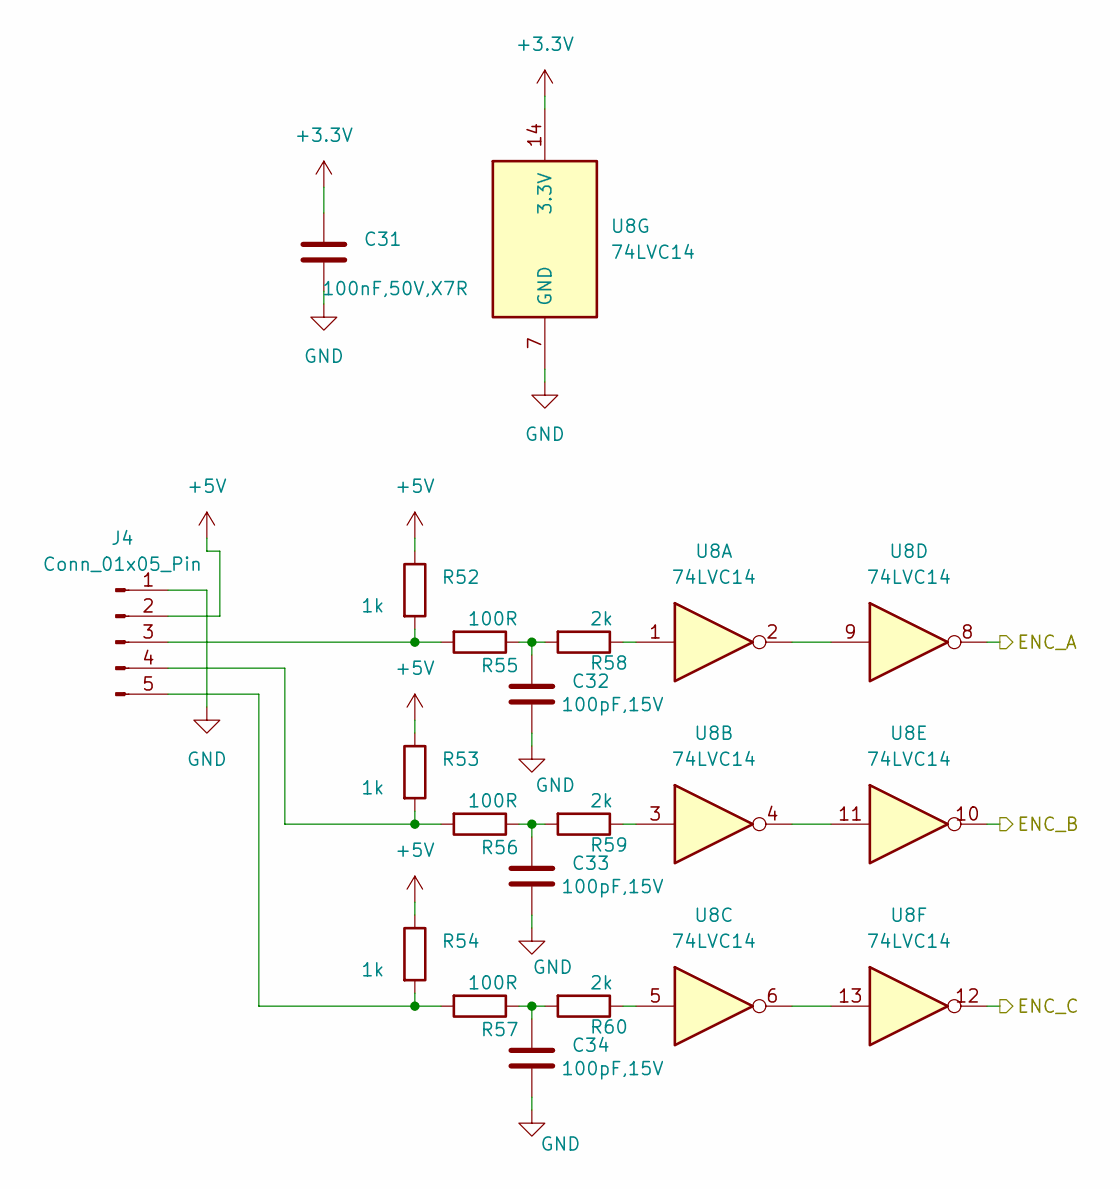
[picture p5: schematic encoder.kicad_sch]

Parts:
C31: 100nF,50V,X7R; C_0805_2012Metric_Pad1.18x1.45mm_HandSolder
C32, C33, C34: 100pF,15V; C_0805_2012Metric_Pad1.18x1.45mm_HandSolder
J4: Conn_01x05_Pin; PinHeader_1x05_P2.54mm_Vertical
R52, R53, R54: 1k; R_0805_2012Metric_Pad1.20x1.40mm_HandSolder
R55, R56, R57: 100R; R_0805_2012Metric_Pad1.20x1.40mm_HandSolder
R58, R59, R60: 2k; R_0805_2012Metric_Pad1.20x1.40mm_HandSolder
U8: 74LVC14

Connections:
+3.3V: C31.1, U8.14 (3.3V); also elsewhere on the board
+5V: J4.2, R52.1, R53.1, R54.1; also elsewhere on the board
/encoder/ENC_A: U8.8; also elsewhere on the board
/encoder/ENC_B: U8.10; also elsewhere on the board
/encoder/ENC_C: U8.12; also elsewhere on the board
GND: C31.2, C32.2, C33.2, C34.2, J4.1, U8.7 (GND); also elsewhere on the board
unnamed: C32.1, R55.1, R58.2
unnamed: C33.1, R56.1, R59.2
unnamed: C34.1, R57.1, R60.2
unnamed: J4.3, R52.2, R55.2
unnamed: J4.4, R53.2, R56.2
unnamed: J4.5, R54.2, R57.2
unnamed: R58.1, U8.1
unnamed: R59.1, U8.3
unnamed: R60.1, U8.5
unnamed: U8.2, U8.9
unnamed: U8.4, U8.11
unnamed: U8.6, U8.13

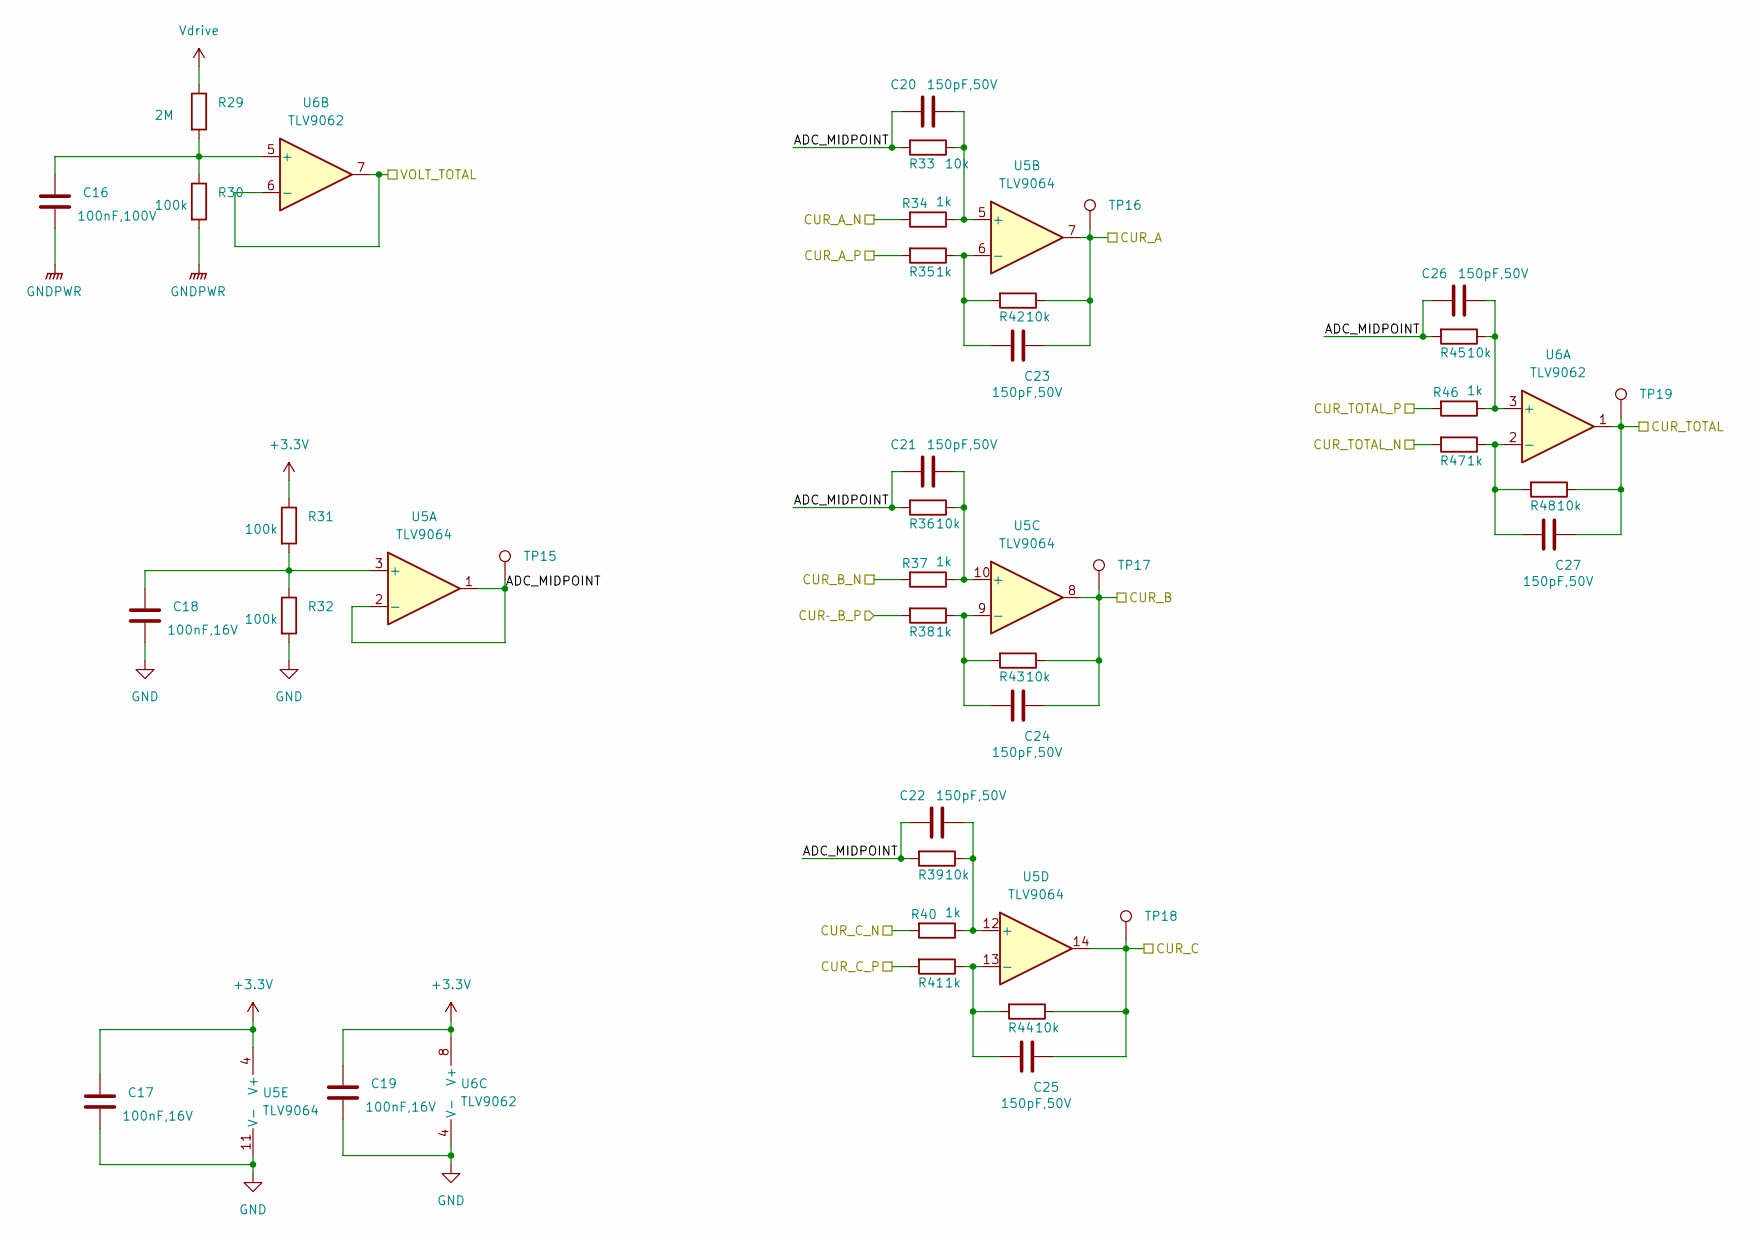
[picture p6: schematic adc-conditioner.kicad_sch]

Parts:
C16: 100nF,100V; C_0805_2012Metric_Pad1.18x1.45mm_HandSolder
C17, C18, C19: 100nF,16V; C_0805_2012Metric_Pad1.18x1.45mm_HandSolder
C20, C21, C22, C23, C24, C25, C26, C27: 150pF,50V; C_0805_2012Metric_Pad1.18x1.45mm_HandSolder
R29: 2M; R_0805_2012Metric_Pad1.20x1.40mm_HandSolder
R30, R31, R32: 100k; R_0805_2012Metric_Pad1.20x1.40mm_HandSolder
R33, R36, R39, R42, R43, R44, R45, R48: 10k; R_0805_2012Metric_Pad1.20x1.40mm_HandSolder
R34, R35, R37, R38, R40, R41, R46, R47: 1k; R_0805_2012Metric_Pad1.20x1.40mm_HandSolder
TP15, TP16, TP17, TP18, TP19: TestPoint; TestPoint_Pad_1.0x1.0mm
U5: TLV9064; SOIC-14_3.9x8.7mm_P1.27mm
U6: TLV9062

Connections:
+3.3V: C17.1, C19.1, R31.1, U5.4 (V+), U6.8 (V+); also elsewhere on the board
/adc-conditioner/ADC_MIDPOINT: C20.1, C21.1, C22.1, C26.1, R33.2, R36.2, R39.2, R45.2, TP15.1 (1_1), U5.1, U5.2 (-)
/adc-conditioner/CUR_A: C23.1, R42.1, TP16.1 (1_1), U5.7; also elsewhere on the board
/adc-conditioner/CUR_A_N: R34.2; also elsewhere on the board
/adc-conditioner/CUR_A_P: R35.2; also elsewhere on the board
/adc-conditioner/CUR_B: C24.1, R43.1, TP17.1 (1_1), U5.8; also elsewhere on the board
/adc-conditioner/CUR_B_N: R37.2; also elsewhere on the board
/adc-conditioner/CUR_C: C25.1, R44.1, TP18.1 (1_1), U5.14; also elsewhere on the board
/adc-conditioner/CUR_C_N: R40.2; also elsewhere on the board
/adc-conditioner/CUR_C_P: R41.2; also elsewhere on the board
/adc-conditioner/CUR_TOTAL: C27.1, R48.1, TP19.1 (1_1), U6.1; also elsewhere on the board
/adc-conditioner/CUR_TOTAL_N: R47.2; also elsewhere on the board
/adc-conditioner/CUR_TOTAL_P: R46.2; also elsewhere on the board
/adc-conditioner/CUR­_B_P: R38.2; also elsewhere on the board
/adc-conditioner/VOLT_TOTAL: U6.6 (-), U6.7; also elsewhere on the board
GND: C17.2, C18.2, C19.2, R32.2, U5.11 (V-), U6.4 (V-); also elsewhere on the board
GNDPWR: C16.2, R30.2; also elsewhere on the board
unnamed: C18.1, R31.2, R32.1, U5.3 (+)
unnamed: C20.2, R33.1, R34.1, U5.5 (+)
unnamed: C23.2, R35.1, R42.2, U5.6 (-)
unnamed: C21.2, R36.1, R37.1, U5.10 (+)
unnamed: C24.2, R38.1, R43.2, U5.9 (-)
unnamed: C22.2, R39.1, R40.1, U5.12 (+)
unnamed: C25.2, R41.1, R44.2, U5.13 (-)
unnamed: C26.2, R45.1, R46.1, U6.3 (+)
unnamed: C27.2, R47.1, R48.2, U6.2 (-)
unnamed: C16.1, R29.2, R30.1, U6.5 (+)
Vdrive: R29.1; also elsewhere on the board

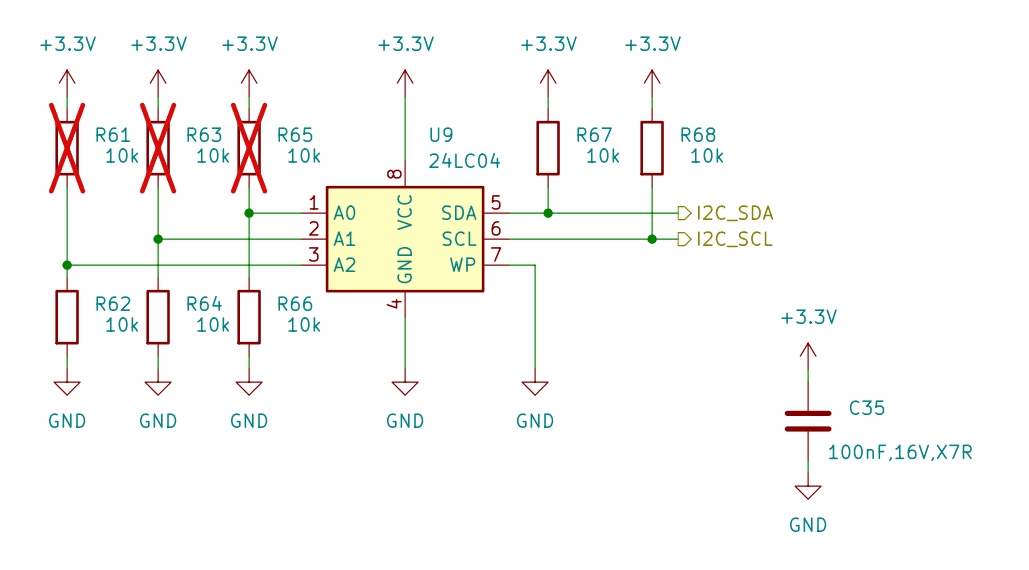
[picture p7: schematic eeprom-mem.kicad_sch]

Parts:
C35: 100nF,16V,X7R; C_0805_2012Metric_Pad1.18x1.45mm_HandSolder
R61, R63, R65: 10k; R_0805_2012Metric_Pad1.20x1.40mm_HandSolder; not fitted
R62, R64, R66, R67, R68: 10k; R_0805_2012Metric_Pad1.20x1.40mm_HandSolder
U9: 24LC04; SOIC-8_3.9x4.9mm_P1.27mm

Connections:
+3.3V: C35.1, R61.1, R63.1, R65.1, R67.1, R68.1, U9.8 (VCC); also elsewhere on the board
/eeprom-mem/I2C_SCL: R68.2, U9.6 (SCL); also elsewhere on the board
/eeprom-mem/I2C_SDA: R67.2, U9.5 (SDA); also elsewhere on the board
GND: C35.2, R62.2, R64.2, R66.2, U9.4 (GND), U9.7 (WP); also elsewhere on the board
unnamed: R65.2, R66.1, U9.1 (A0)
unnamed: R63.2, R64.1, U9.2 (A1)
unnamed: R61.2, R62.1, U9.3 (A2)

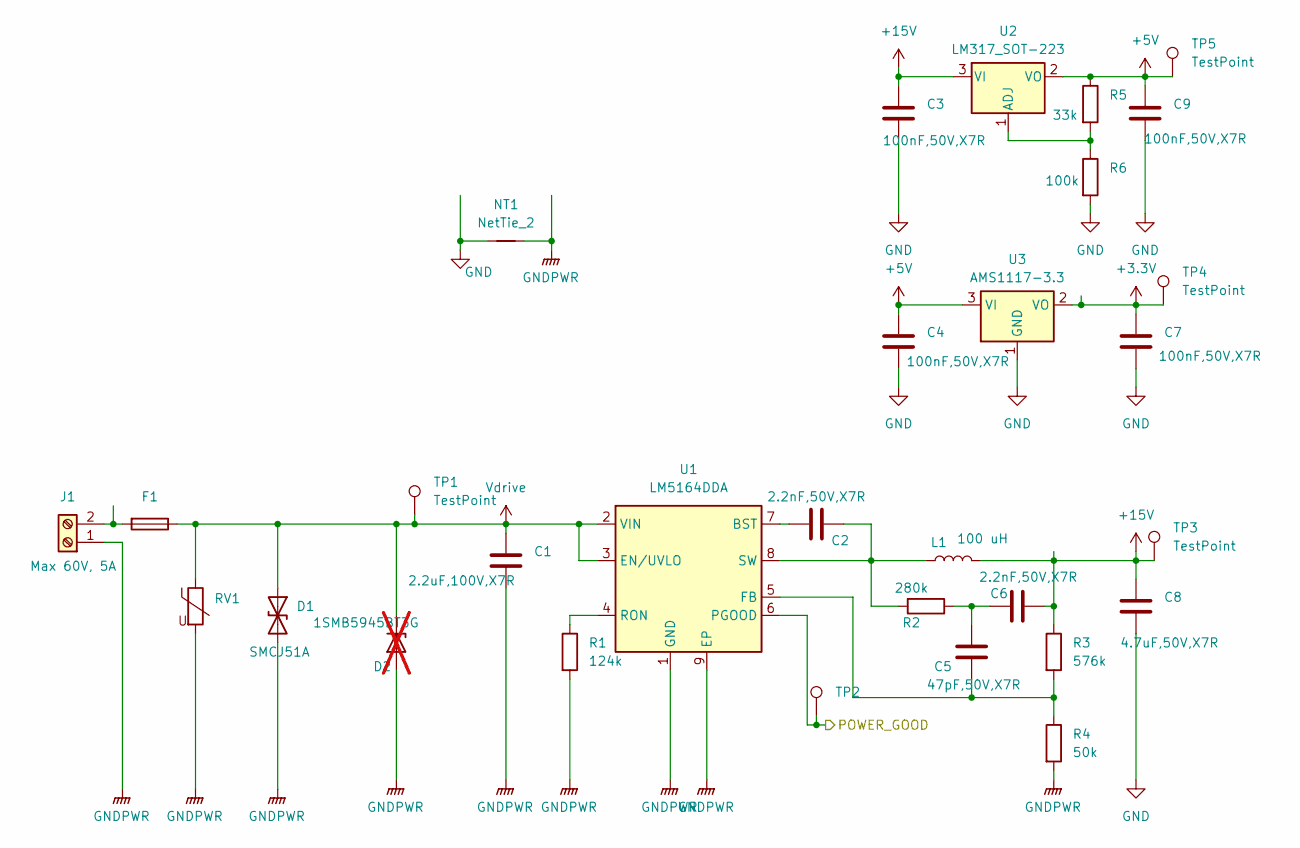
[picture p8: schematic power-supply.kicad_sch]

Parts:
C1: 2.2uF,100V,X7R; C_0805_2012Metric_Pad1.18x1.45mm_HandSolder
C2, C6: 2.2nF,50V,X7R; C_0805_2012Metric_Pad1.18x1.45mm_HandSolder
C3, C4, C7, C9: 100nF,50V,X7R; C_0805_2012Metric_Pad1.18x1.45mm_HandSolder
C5: 47pF,50V,X7R; C_0805_2012Metric_Pad1.18x1.45mm_HandSolder
C8: 4.7uF,50V,X7R; C_0805_2012Metric_Pad1.18x1.45mm_HandSolder
D1: SMCJ51A; D_SMC
D2: 1SMB5945BT3G; D_SMB; not fitted
F1: Fuse; Fuse_1812_4532Metric
J1: Screw_Terminal_01x02; TerminalBlock_CUI_TB007-508-02_1x02_P5.08mm_Horizontal
L1: 100 uH; L_7.3x7.3_H4.5
NT1: NetTie_2; NetTie-2_SMD_Pad2.0mm
R1: 124k; R_0805_2012Metric_Pad1.20x1.40mm_HandSolder
R2: 280k; R_0805_2012Metric_Pad1.20x1.40mm_HandSolder
R3: 576k; R_0805_2012Metric_Pad1.20x1.40mm_HandSolder
R4: 50k; R_0805_2012Metric_Pad1.20x1.40mm_HandSolder
R5: 33k; R_0805_2012Metric_Pad1.20x1.40mm_HandSolder
R6: 100k; R_0805_2012Metric_Pad1.20x1.40mm_HandSolder
RV1: Varistor; Fuse_1812_4532Metric
TP1, TP2, TP3, TP4, TP5: TestPoint; TestPoint_Pad_1.0x1.0mm
U1: LM5164DDA; HSOP-8-1EP_3.9x4.9mm_P1.27mm_EP2.41x3.1mm
U2: LM317_SOT-223; SOT-223-3_TabPin2
U3: AMS1117-3.3; SOT-223-3_TabPin2

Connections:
+3.3V: C7.1, TP4.1 (1_1), U3.2 (VO); also elsewhere on the board
+5V: C4.1, C9.1, R5.1, TP5.1 (1_1), U2.2 (VO), U3.3 (VI); also elsewhere on the board
+15V: C3.1, C6.1, C8.1, L1.2, R3.1, TP3.1 (1_1), U2.3 (VI); also elsewhere on the board
/microcontroller-connector/POWER_GOOD: TP2.1 (1_1), U1.6 (PGOOD); also elsewhere on the board
GND: C3.2, C4.2, C7.2, C8.2, C9.2, NT1.1, R6.2, U3.1 (GND); also elsewhere on the board
GNDPWR: C1.2, D1.2 (A2), D2.2 (A), J1.1, NT1.2, R1.2, R4.2, RV1.2, U1.1 (GND), U1.9 (EP); also elsewhere on the board
unnamed: C5.1, C6.2, R2.1
unnamed: F1.2, J1.2
unnamed: C2.2, U1.7 (BST)
unnamed: C5.2, R3.2, R4.1, U1.5 (FB)
unnamed: R1.1, U1.4 (RON)
unnamed: C2.1, L1.1, R2.2, U1.8 (SW)
unnamed: R5.2, R6.1, U2.1 (ADJ)
Vdrive: C1.1, D1.1 (A1), D2.1 (K), F1.1, RV1.1, TP1.1 (1_1), U1.2 (VIN), U1.3 (EN/UVLO); also elsewhere on the board

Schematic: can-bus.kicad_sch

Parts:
C28, C29: 100nF,16V,X7R; C_0805_2012Metric_Pad1.18x1.45mm_HandSolder
C30: 4.7nF; C_0805_2012Metric_Pad1.18x1.45mm_HandSolder
D6: NUP2105L; SOT-23W_Handsoldering
J3: Screw_Terminal_01x03; TerminalBlock_Xinya_XY308-2.54-3P_1x03_P2.54mm_Horizontal
R49: 0R; R_0805_2012Metric_Pad1.20x1.40mm_HandSolder
R50, R51: 60R; R_0805_2012Metric_Pad1.20x1.40mm_HandSolder
U7: SN65HVD230; SOIC-8_3.9x4.9mm_P1.27mm

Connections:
+3.3V: C29.1, U7.3 (VCC); also elsewhere on the board
/can-bus/CAN_RX: U7.4 (R); also elsewhere on the board
/can-bus/CAN_TX: U7.1 (D); also elsewhere on the board
GND: C28.2, C29.2, C30.2, D6.3 (A), J3.2, R49.2, U7.2 (GND); also elsewhere on the board
unnamed: C30.1, R50.2, R51.1
unnamed: D6.2 (K), J3.1, R50.1, U7.7 (CANH)
unnamed: D6.1 (K), J3.3, R51.2, U7.6 (CANL)
unnamed: R49.1, U7.8 (Rs)
unnamed: C28.1, U7.5 (Vref)

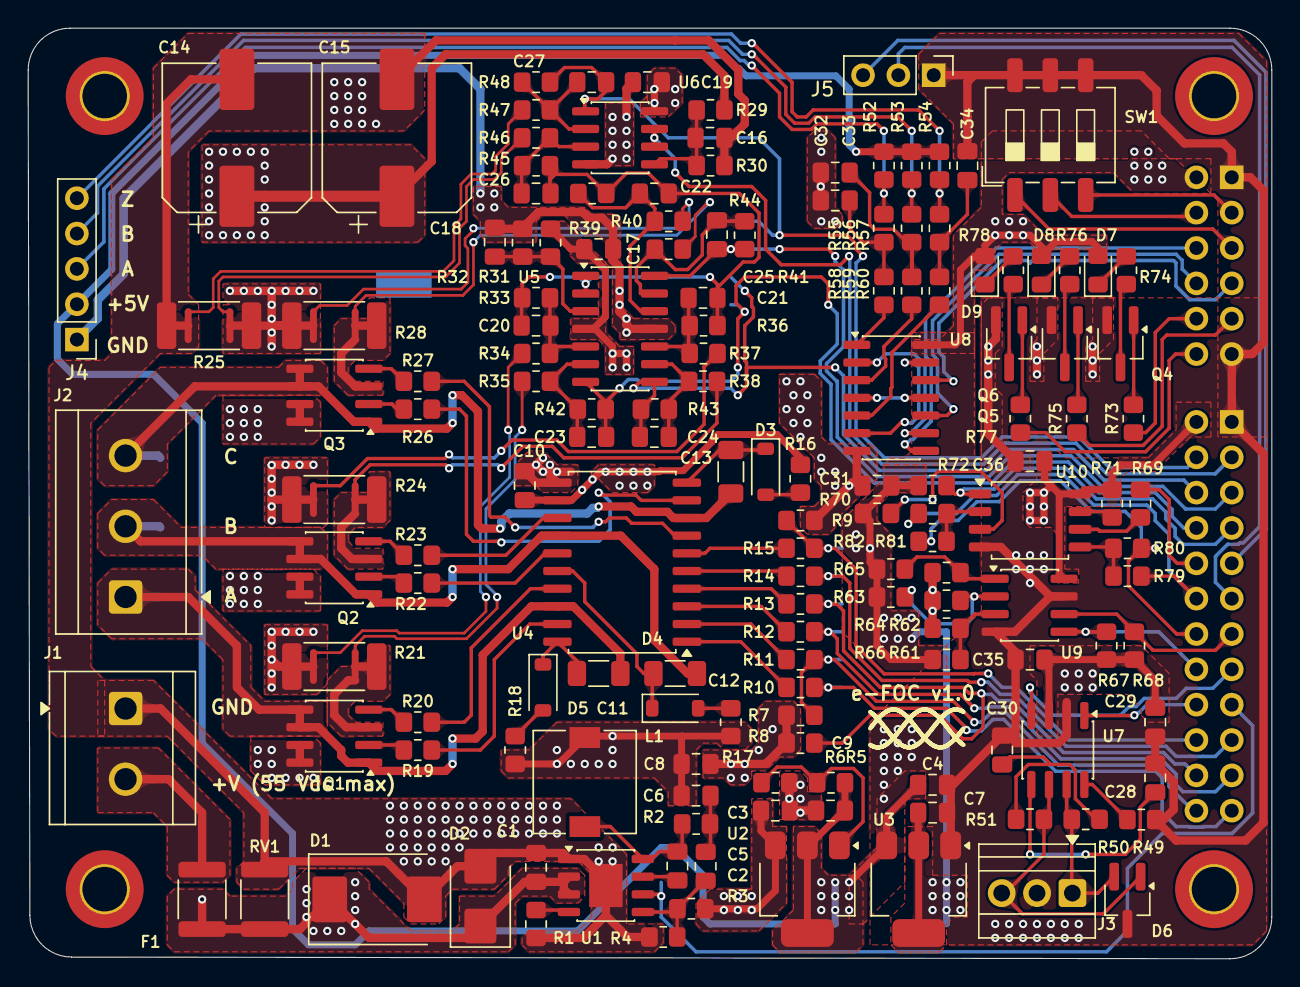
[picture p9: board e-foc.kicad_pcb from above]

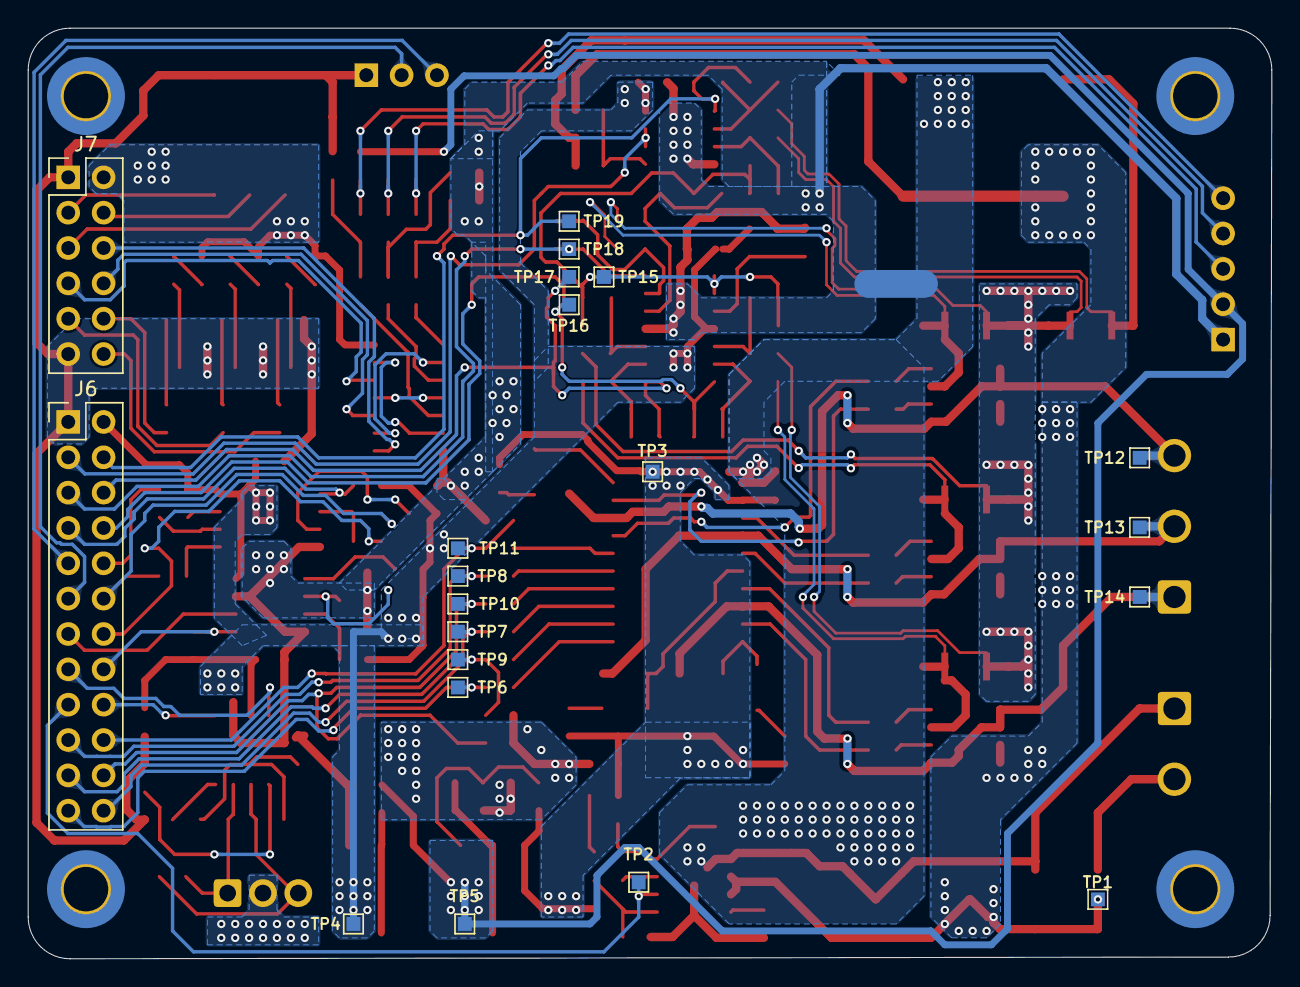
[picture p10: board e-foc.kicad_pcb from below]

Board: 2 copper layers, 89.4 x 66.9 mm, 186 parts (22 on the bottom side), 128 nets.

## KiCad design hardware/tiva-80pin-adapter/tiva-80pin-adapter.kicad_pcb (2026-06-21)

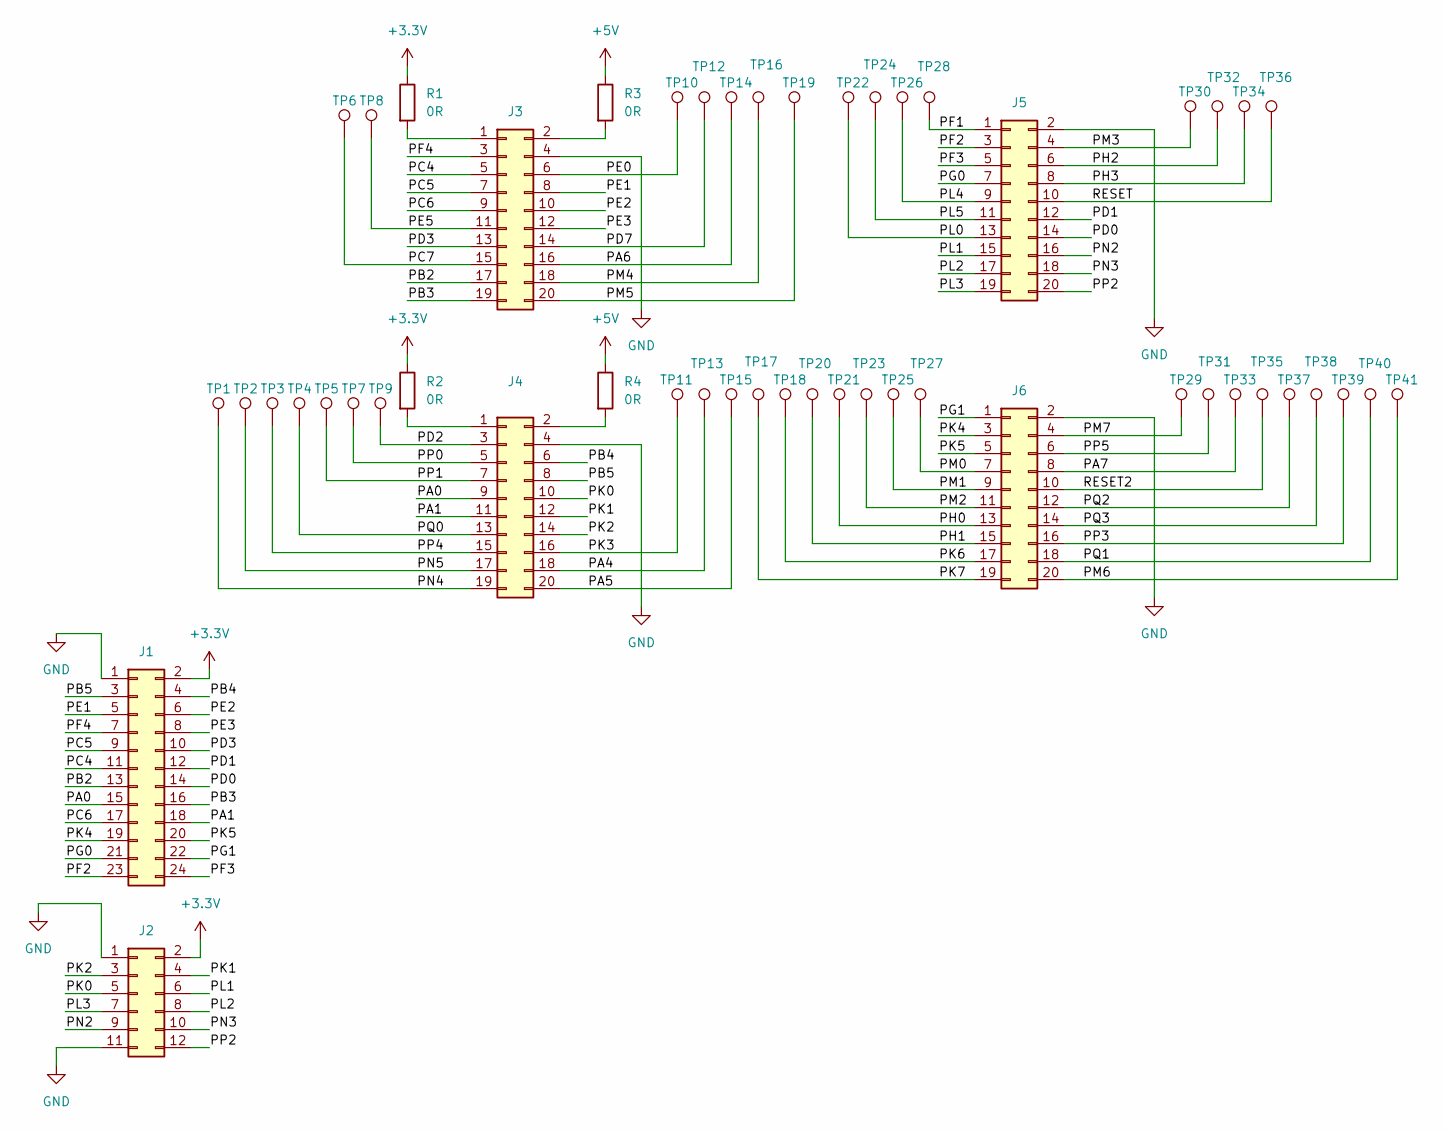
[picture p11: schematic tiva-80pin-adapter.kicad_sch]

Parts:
J1: Conn_02x12_Odd_Even; PinHeader_2x12_P2.54mm_Vertical
J2: Conn_02x06_Odd_Even; PinHeader_2x06_P2.54mm_Vertical
J3, J4, J5, J6: Conn_02x10_Odd_Even; PinHeader_2x10_P2.54mm_Vertical
R1, R2, R3, R4: 0R; R_0805_2012Metric_Pad1.20x1.40mm_HandSolder
TP1, TP2, TP3, TP4, TP5, TP6, TP7, TP8, TP9, TP10, TP11, TP12, TP13, TP14, TP15, TP16, TP17, TP18, TP19, TP20, TP21, TP22, TP23, TP24, TP25, TP26, TP27, TP28, TP29, TP30, TP31, TP32, TP33, TP34, TP35, TP36, TP37, TP38, TP39, TP40, TP41: TestPoint; TestPoint_Pad_D2.0mm

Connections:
+3.3V: J1.2, J2.2, R1.1, R2.1
+5V: R3.1, R4.1
/PA0: J1.15, J4.9
/PA1: J1.18, J4.11
/PA4: J4.18, TP13.1 (1_1)
/PA5: J4.20, TP15.1 (1_1)
/PA6: J3.16, TP14.1 (1_1)
/PA7: J6.8, TP33.1 (1_1)
/PB2: J1.13, J3.17
/PB3: J1.16, J3.19
/PB4: J1.4, J4.6
/PB5: J1.3, J4.8
/PC4: J1.11, J3.5
/PC5: J1.9, J3.7
/PC6: J1.17, J3.9
/PC7: J3.15, TP6.1 (1_1)
/PD0: J1.14, J5.14
/PD1: J1.12, J5.12
/PD2: J4.3, TP9.1 (1_1)
/PD3: J1.10, J3.13
/PD7: J3.14, TP12.1 (1_1)
/PE0: J3.6, TP10.1 (1_1)
/PE1: J1.5, J3.8
/PE2: J1.6, J3.10
/PE3: J1.8, J3.12
/PE5: J3.11, TP8.1 (1_1)
/PF1: J5.1, TP28.1 (1_1)
/PF2: J1.23, J5.3
/PF3: J1.24, J5.5
/PF4: J1.7, J3.3
/PG0: J1.21, J5.7
/PG1: J1.22, J6.1
/PH0: J6.13, TP21.1 (1_1)
/PH1: J6.15, TP20.1 (1_1)
/PH2: J5.6, TP32.1 (1_1)
/PH3: J5.8, TP34.1 (1_1)
/PK0: J2.5, J4.10
/PK1: J2.4, J4.12
/PK2: J2.3, J4.14
/PK3: J4.16, TP11.1 (1_1)
/PK4: J1.19, J6.3
/PK5: J1.20, J6.5
/PK6: J6.17, TP18.1 (1_1)
/PK7: J6.19, TP17.1 (1_1)
/PL0: J5.13, TP22.1 (1_1)
/PL1: J2.6, J5.15
/PL2: J2.8, J5.17
/PL3: J2.7, J5.19
/PL4: J5.9, TP26.1 (1_1)
/PL5: J5.11, TP24.1 (1_1)
/PM0: J6.7, TP27.1 (1_1)
/PM1: J6.9, TP25.1 (1_1)
/PM2: J6.11, TP23.1 (1_1)
/PM3: J5.4, TP30.1 (1_1)
/PM4: J3.18, TP16.1 (1_1)
/PM5: J3.20, TP19.1 (1_1)
/PM6: J6.20, TP41.1 (1_1)
/PM7: J6.4, TP29.1 (1_1)
/PN2: J2.9, J5.16
/PN3: J2.10, J5.18
/PN4: J4.19, TP1.1 (1_1)
/PN5: J4.17, TP2.1 (1_1)
/PP0: J4.5, TP7.1 (1_1)
/PP1: J4.7, TP5.1 (1_1)
/PP2: J2.12, J5.20
/PP3: J6.16, TP39.1 (1_1)
/PP4: J4.15, TP3.1 (1_1)
/PP5: J6.6, TP31.1 (1_1)
/PQ0: J4.13, TP4.1 (1_1)
/PQ1: J6.18, TP40.1 (1_1)
/PQ2: J6.12, TP37.1 (1_1)
/PQ3: J6.14, TP38.1 (1_1)
/RESET: J5.10, TP36.1 (1_1)
/RESET2: J6.10, TP35.1 (1_1)
GND: J1.1, J2.1, J2.11, J3.4, J4.4, J5.2, J6.2
unnamed: J3.1, R1.2
unnamed: J3.2, R3.2
unnamed: J4.1, R2.2
unnamed: J4.2, R4.2

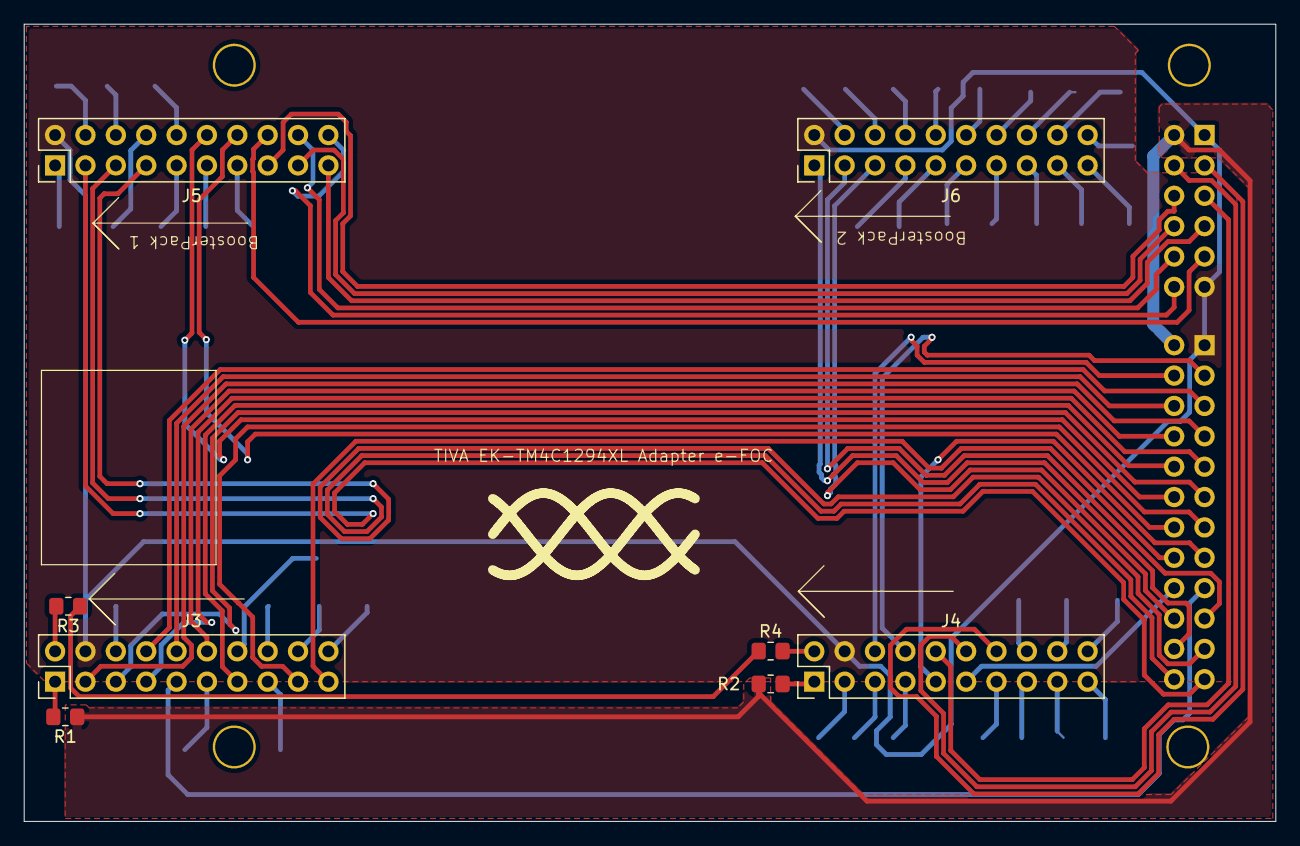
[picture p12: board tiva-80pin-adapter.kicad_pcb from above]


Board: 2 copper layers, 104.7 x 66.7 mm, 51 parts (43 on the bottom side), 79 nets.

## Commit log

2026-06-21 chore: add release please action (#1)
    * add release please action
    * refactor structure
    * schematic finished
    * pcb improvements
    * board finished
    * updates
    * updates
    * .\.claude\
    * updates
    * reorganize project
    * fix ci
    * fix ci
    * fix(ci): disable kicad-bot bom/diff (not implemented in v0.1.3)
    verify (ERC/DRC) passes, but run-bom-check and run-diff exit 2 with
    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
    [adc-conditioner.kicad_sch, can-bus.kicad_sch, driver.kicad_sch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]
2026-06-21 chore: enable all commit types and cut v1.0.0 (#3)
    * chore: enable all commit types and cut v1.0.0
    Unhide every predefined Conventional Commit type in changelog-sections so
    non-feat/fix commits (chore, docs, ci, etc.) count as user-facing and trigger
    releases. Set release-as to 1.0.0 to cut the first release.
    * ci: run kicad-bot and kicad-diff on any file change
    Drop the paths filters so both workflows trigger on every push to main and
    every pull request, not only when KiCad design files change.
    ---------
2026-06-21 chore: drop release-as pin after v1.0.0 (#5)
    v1.0.0 is cut (tag + release exist, manifest reads 1.0.0). Remove the
    release-as override so release-please resumes normal SemVer bumps from
    Conventional Commits instead of staying pinned at 1.0.0.
2026-06-21 docs: add component-agnostic FOC hardware design guide (#7)
    Add docs/foc-hardware-design-guide.md - an interface-style body of knowledge covering power supply, gate drive, the H-bridge power stage, over-voltage/current/temperature protection, current sensing, thermal design, PCB-layout priority order, and KiCad tips (placement, teardrops, mask, pour, DRC, ERC).
    Wire the foc-board-reviewer agent to use the guide as its rubric and knowledge base; the board README/spec stays the binding contract.

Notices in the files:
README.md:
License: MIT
